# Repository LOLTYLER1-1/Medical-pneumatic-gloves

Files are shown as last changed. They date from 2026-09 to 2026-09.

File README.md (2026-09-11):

# 医用气动辅助手套 (Medical Pneumatic Assistive Glove)

> 基于 **正点原子领航者 V3.9 ZYNQ7020** + **7" 800×480 触摸 LCD** 的手指被动康复训练装置
> PL(FPGA) + PS(ARM) 协同实现，不依赖外部 MCU
> 创建：2026-05-11 ｜ 最新修订：2026-08-16（台架联调打通）

---

## 项目简介

面向脑卒中后手指屈曲挛缩、神经损伤患者的手指 **被动屈伸训练** 装置：

- **摸左半屏** → 气泵加压到设定值（默认 50 kPa）自动停止，手套气室鼓胀带动手指屈曲
- **摸右半屏** → 泄气阀打开，自然回弹松手
- LCD 实时显示压力数值（`XXX.XX KPA` 大字）、状态色条、压力条
- **三层安全保护**：PL 端纯组合逻辑硬件强切（≥80 kPa 泵阀双断）、板载 KEY1 急停、
  传感器故障检测（通信失败 2~3 秒内蜂鸣 + 自动泄气锁定）
- 泄气阀选用 **常开型 (NO)**：断电自动泄压，fail-safe

### 工作原理一句话

```
摸 LCD → GT911(PS 端 EMIO 软件 IIC) → ZYNQ7020 → PCB 驱动板 → 气泵/泄气阀 → 手套气室
                                        ↑                    │
                                        └── XGZP6857D 气压传感器 (IIC 闭环反馈) ──┘
```

📹 **演示视频**：
- [`无气压传感器版实验演示_2026-09-04.mp4`](./无气压传感器版实验演示_2026-09-04.mp4)（无气压传感器版本实验，2026-09-04）
- [`简易版实验结果演示.mp4`](./简易版实验结果演示.mp4)（仿真压力模式，气球抓握演示，2026-08）
🖼️ **定稿电路图**：[`最终电路图.png`](./最终电路图.png)

---

## 当前状态（2026-08-16）

| 项 | 状态 |
|---|---|
| PL 端 13 个 Verilog 模块 + XDC + 比特流 | ✅ 完成并上板验证 |
| GT911 触摸（复位时序根因已修复） | ✅ 左右半屏充/泄请求完好 |
| PS 端 Vitis 应用（EMIO / DCC 日志 / 心跳 LED） | ✅ 完成 |
| 驱动板 PCB（立创EDA 工程 + Gerber，三重验证） | ✅ 2026-07-30 完成 |
| 台架联调（仿真压力模式气球演示） | ✅ 2026-08-04 成功 |
| 真实压力闭环 | ⏳ 等重买 XGZP6857D **IIC 数字版**（旧传感器疑似焊接烫死），到手后 `SIM_PRESSURE` 改 0 |
| 遗留硬件 | ⏳ 12V GND 与 ATK GND 需并 2~3 根地线（治地弹负尖峰）；ULN2803 COM 接 12V 待确认 |

---

## 仓库结构

```
medical project/
├─ README.md                        ← 本文件
├─ 最终电路图.png                    ← 定稿电路图 (4400×3300, 全元件覆盖)
├─ 简易版实验结果演示.mp4             ← 台架演示视频 (2026-08)
├─ 无气压传感器版实验演示_2026-09-04.mp4 ← 无气压传感器版实验视频 (2026-09-04)
├─ lcd_image.coe                    ← LCD 中心图片初始化文件 (200×175 RGB565)
│
├─ 01_思维导图/项目思维导图.md         ← 系统全景、里程碑、开发顺序
├─ 02_原理图/
│   ├─ 系统原理图.md                 ← 框图/气路/电气连接/引脚表/台架联调记录
│   └─ gen_final_circuit.py         ← 定稿电路图生成脚本 (改后重跑出新图)
│
├─ 03_元件清单/
│   ├─ 元件采购清单.md               ← 采购方案与注意事项
│   ├─ 最终元件清单_2026-07-21.md/.png  ← ★ 权威 BOM
│   ├─ 淘宝直搜词清单_2026-07-22.md/.png ← 下单搜索关键词
│   └─ XGZP6857D_引脚图.png          ← 传感器引脚辨别图
│
├─ 05_FPGA_PL/                      ← PL 端 Verilog (Vivado 2020.2)
│   ├─ 00_top/ ~ 12_pressure_model/ ← 13 个模块, 每个都有干净版+逐行注释教学版
│   ├─ constraints/medical_glove.xdc
│   ├─ sim/                         ← Testbench + Python 事务级/比特级仿真脚本
│   └─ README.md                    ← Vivado 工程重建步骤 (IP/BD 配置)
│
├─ 06_PS/                           ← PS 端 ARM 软件 (Vitis 2020.2)
│   ├─ system_top.xsa               ← 硬件移交文件 (含比特流)
│   └─ VITIS/medical_glove_app/src/ ← 应用源码 (main/ft5206/touch/myiic/emio_iic_cfg)
│
└─ 07_PCB/                          ← 驱动板 PCB (立创EDA 专业版)
    ├─ 医用手套驱动板.epro            ← 完整工程, 可直接打开/编辑/下单
    ├─ 医用手套驱动板_gerber.zip       ← 打板生产文件 (2层 90×68mm 全直插)
    ├─ 验证报告.md / 下单与使用指南.md
    └─ gen_pcb.py 等                 ← PCB 自动生成与校验脚本
```

---

## 硬件连接要点（ATK MODULE U4 排针，唯一外接点）

ATK 口丝印是历史名称（UART 模块用），实际就是 4 个普通 FPGA IO：

| ATK 丝印 | FPGA 引脚 | 本项目信号 |
|---|---|---|
| LED | N15 | 气压传感器 SCL |
| KEY | G14 | 气压传感器 SDA |
| RXD | T19 | 气泵驱动 (→100R→IRLZ44N 栅极) |
| TXD | J15 | 泄气阀驱动 (→ULN2803 IN1) |
| GND | — | 共地（**12V 适配器负极必须接这里，并 2~3 根地线**） |
| VCC | — | +5V（仅传感器/上拉电源，禁带泵阀） |

板载资源（免外接）：LED0=H15 状态/心跳，KEY1=K16 急停，蜂鸣器=M14 告警，KEY_RST=N16 复位。

---

## 快速开始

1. 读文档：[思维导图](./01_思维导图/项目思维导图.md) → [系统原理图](./02_原理图/系统原理图.md) → [元件清单](./03_元件清单/最终元件清单_2026-07-21.md)
2. PL 重建：按 [`05_FPGA_PL/README.md`](./05_FPGA_PL/README.md) 新建 Vivado 2020.2 工程
   （器件 `xc7z020clg400-2`，需配 `clk_wiz_0` + `lcd_image_rom` 两个 IP + PS7 Block Design）
3. PS 重建：Vitis 2020.2 导入 `06_PS/system_top.xsa`，新建应用加入 `06_PS/VITIS/medical_glove_app/src/`
4. 无传感器演示：`medical_glove_top.v` 中 `SIM_PRESSURE=1`（仿真压力模型顶替传感器）；
   传感器到位后改 0 恢复真实闭环
5. 打板：`07_PCB/医用手套驱动板_gerber.zip` 直接上传嘉立创下单

---

## 安全声明

⚠️ 本项目为 **学习实验作品**，不是医疗器械，禁止替代正规康复治疗。
任何穿戴测试前，必须先用气球/瓶罐做负载验证；压力硬上限 80 kPa 由 PL 纯组合逻辑强切，
泄气阀断电自动打开（fail-safe）。

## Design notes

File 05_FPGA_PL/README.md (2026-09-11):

# 05_FPGA_PL端 - Verilog 工程

> 医用气动辅助手套 - ZYNQ7020 PL 端
> 工具链: Vivado 2020.2
> 顶层模块: **`00_top/medical_glove_top.v`** ★

---

## 一、文件结构

```
05_FPGA_PL/
├── README.md                                  本文件
├── 00_top/
│   ├── medical_glove_top.v                    顶层 (综合用, 含 SIM_PRESSURE 参数)
│   ├── medical_glove_top_annotated.v          顶层 (教学版)
│   └── system_top.v                           连接 BD wrapper + glove 顶层的包装
├── 01_clock_reset/                            时钟/复位 (依赖 clk_wiz_0)
├── 02_key_debounce/                           按键消抖
├── 03_lcd_timing/                             LCD 行场时序
├── 04_lcd_display/                            UI 渲染 (含压力数值 BCD 字库)
├── 05_touch_iic/                              触摸 IIC 主机 (★ 早期方案, 最终触摸走 PS EMIO)
├── 06_pressure_iic/                           XGZP6857D 气压 IIC 主机 (官方规格书重写版)
├── 07_pwm_ctrl/                               气泵软启动 PWM
├── 08_glove_fsm/                              主状态机
├── 09_safety_interlock/                       硬件安全联锁 (纯组合)
├── 10_axi_lite_reg/                           EMIO 旁路寄存器
├── 11_buzzer/                                 蜂鸣器 2Hz 告警 (板载 M14)
├── 12_pressure_model/                         仿真压力模型 (SIM_PRESSURE=1 时顶替传感器)
├── ip_sources/lcd_image.coe                   屏幕中心图片初始化文件 (200x175 RGB565)
├── constraints/medical_glove.xdc              引脚约束
├── sim/                                       Testbench + Python 仿真验证脚本
├── vivado_bd_emio_fix.tcl                     BD EMIO 修复脚本
└── 用户操作清单.docx                           Vivado 操作步骤记录
```

每个子目录里:
- `xxx.v`           = 干净版 (加入 Vivado 工程综合)
- `xxx_annotated.v` = 教学版 (每行注释, **不要加入工程**)

---

## 二、需要在 Vivado 中创建的 IP 核

需要 **2 个 IP** + **PS7 (Block Design 添加)**:

### IP 1: Clocking Wizard `clk_wiz_0`

**作用**: 50 MHz → 100 MHz + 33.33 MHz

**创建步骤**:
1. Vivado → `IP Catalog` → 搜索 `Clocking Wizard` → 双击
2. 在 `Clocking Options` 选项卡:
   - Primary: `Single ended clock capable pin`
   - Source frequency: `50.000` MHz
3. 在 `Output Clocks` 选项卡:
   - `clk_out1` 勾选, 频率填 `100.000`
   - `clk_out2` 勾选, 频率填 `33.333`
   - `reset type` 选 `Active Low` (与 RTL 中的 `resetn` 端口匹配)
   - 勾选 `locked` 输出
4. Component Name 保持默认 `clk_wiz_0` → OK → Generate

### IP 2: Block Memory Generator `lcd_image_rom` (屏幕中心图片)

**作用**: 存放 200x175 RGB565 图片, 给 `lcd_display.v` 模块读取

**创建步骤**:
1. Vivado → `IP Catalog` → 搜索 `Block Memory Generator` → 双击
2. `Component Name` 必须填 **`lcd_image_rom`** (与 lcd_display.v 例化名一致)
3. `Basic` 选项卡:
   - Interface Type: `Native`
   - Memory Type: **`Single Port ROM`**
4. `Port A Options` 选项卡:
   - Port A Width: **`16`**  (RGB565)
   - Port A Depth: **`35000`** (= 200 × 175)
   - Enable Port Type: `Always Enabled`
   - **取消勾选** `Primitive Output Register` (减少 1 拍延迟; 不取消则需要再加 1 级 pipeline)
   - 实际默认 1 拍延迟即可, RTL 代码已按 1 拍延迟对齐
5. `Other Options` 选项卡:
   - **勾选** `Load Init File`
   - Coe File: 点 `Browse` 选 `<工程目录>/ip_sources/lcd_image.coe`
   - 等校验通过 (会显示像素数 = 35000)
6. → OK → Generate Output Products

**图片位置**:
- 屏幕中心 (300, 152) → (499, 326)
- 屏幕 800×480 减图片 200×175 居中

**RGB565 → RGB888**: 由 RTL 自动做位扩展, 不需关心

### Block Design 中: ZYNQ7 Processing System (PS7)

PS7 不是"创建", 是在 Block Design 里拖一个 IP 进去:

1. `Create Block Design` → 名字 `system`
2. 右键空白 → `Add IP` → 选 `ZYNQ7 Processing System`
3. 双击 PS7 IP 弹出配置:
   - **MIO Configuration**:
     - 关掉所有用不到的(例如 USB/Ethernet/SDIO 按板子实际可用情况)
     - 保留 UART1 (Vitis 串口打印用)
   - **PS-PL Configuration → General → Enable Clock Resets → FCLK_RESET0_N**: 勾选
   - **PS-PL Configuration → AXI Non Secure Enablement → GP Master AXI**: 勾选 M_AXI_GP0
   - **MIO Configuration → I/O Peripherals → GPIO → EMIO GPIO Width**: 填 `64`
     (最终映射: 输出 EMIO[0]=grip_req, [1]=release_req, [17:2]=setpoint(0.01kPa);
      输入 EMIO[15:0]=压力, [18:16]=FSM状态, [19]=safety_trigger, [20]=sensor_fault;
      触摸 IIC 走 EMIO[54:57] = XGpioPs pin 108~111)
   - **Clock Configuration → PL Fabric Clocks → FCLK_CLK0**: 50 MHz (与 PL 系统时钟一致, 但实际我们用板上有源晶振, 这里 FCLK_CLK0 可以不接, 留默认)
4. 点 `Run Block Automation` → 自动连复位

### (可选) Integrated Logic Analyzer `ila_0` - 调试用

仅在仿真后还需在板上抓信号时添加。本工程不强制依赖。

---

## 三、Vivado 工程创建完整步骤

### 1) 新建工程
- File → New Project → Project Type: `RTL Project`
- Default Part: `xc7z020clg400-2`

### 2) 添加源文件 (只添加干净版, 不要添加 `_annotated.v`)
- `Add Sources` → `Add or create design sources`
- 选 13 个子目录里的干净版 .v 文件 (顶层 + system_top + 12 个子模块)
- 添加约束: `constraints/medical_glove.xdc`

### 3) 添加 IP
- `IP Catalog` → Clocking Wizard → 按 §二 IP1 参数配置 → Generate Output Products
- `IP Catalog` → Block Memory Generator → 按 §二 IP2 参数配置 (COE 选 `ip_sources/lcd_image.coe`) → Generate Output Products

### 4) 创建 Block Design
- `Create Block Design` → 加 PS7 → 配置 EMIO GPIO Width = 20
- 把 PS7 的 EMIO GPIO 端口 Make External
- 默认名 `GPIO_0` → 后续顶层需要修改, 见下一节

### 5) 顶层例化 PS7 (二选一)

**方案 A (推荐)**: 把 medical_glove_top.v 当作纯 PL 顶层, PS7 在 Block Design 里通过 EMIO 单向输出/输入信号, 然后在 Block Design 外部再写一个新顶层把两者拼在一起。

**方案 B**: 直接让 BD wrapper 当工程顶层, 在 BD 里例化 medical_glove_top 作为子 IP (需要 Package IP)。

**当前建议**: 调试期用 **方案 A** 快, 后续可重构。

### 6) 综合 / 实现 / 生成比特流
- `Run Synthesis` → 检查 timing
- `Run Implementation`
- `Generate Bitstream`

### 7) 导出硬件给 Vitis
- `File → Export → Export Hardware` → 勾选 Include bitstream
- 进入 `06_PS端软件/` 创建 Vitis 工程

---

## 四、模块层级图

```
                medical_glove_top.v  ★顶层★
                          │
   ┌──────────┬───────────┼───────────┬──────────┬──────────┐
   │          │           │           │          │          │
clock_reset key_debounce lcd_timing lcd_display touch_iic glove_fsm
   │                                              │          │
   └─►clk_wiz_0(IP)                               │          │
                                                  │          │
                                            pressure_iic  pwm_ctrl
                                                            │
                                                       safety_interlock
                                                            │
                                                  (pump_o/v1_o/v2_o)
                          │
                  axi_lite_reg ←──── EMIO ────► PS7 (ARM A9)
```

---

## 五、模块职责一览

| # | 模块 | 角色 | Arduino 类比 |
|---|---|---|---|
| 0 | medical_glove_top ★ | 顶层 | `.ino` 主文件 |
| 1 | clock_reset | 时钟生成 + 复位同步 | 内部定时器 |
| 2 | key_debounce | 物理按键 20ms 消抖 | 按键防抖代码 |
| 3 | lcd_timing | LCD 行场时序 | 屏库底层 |
| 4 | lcd_display | UI 渲染 | tft.fillRect |
| 5 | touch_iic | 触摸 IIC (早期方案, 最终走 PS EMIO 软 IIC, GT911) | Wire.h |
| 6 | pressure_iic | XGZP6857D 读气压 (官方规格书重写版, 带故障检测) | Wire.h 读 BMP |
| 7 | pwm_ctrl | 气泵软启动 PWM | analogWrite() |
| 8 | glove_fsm | 主状态机 | switch(state) |
| 9 | safety_interlock | 硬件安全联锁 | 物理保险丝 |
| 10 | axi_lite_reg | EMIO 接口 | Serial.print() |
| 11 | buzzer_ctrl | 蜂鸣器 2Hz 告警 (M14) | tone() |
| 12 | pressure_model | 仿真压力模型 (演示用) | 假传感器 |

---

## 六、代码风格约定

### 端口命名后缀
- `_i` — input
- `_o` — output
- `_io` — inout (仅 IIC 用)
- `_n` — 低电平有效 (如 `rst_n_i`)

### 信号命名中缀
- `_raw` — 原始信号
- `_clean` — 消抖/同步后
- `_sync` — 跨时钟域同步后

### 双版本约定
- 干净版 `xxx.v` (综合用)
- 教学版 `xxx_annotated.v` (每行注释, 仅作学习)

---

## 七、当前进度 (2026-08-16)

- ✅ 文件夹结构
- ✅ 顶层 medical_glove_top.v 双版本 (含 SIM_PRESSURE 仿真压力开关)
- ✅ 全部 13 个子模块双版本完成 (含 buzzer_ctrl / pressure_model)
- ✅ XDC 约束 (基于官方 NAVIGATOR_ZYNQ_IO.xdc, 已 1:1 对齐; false_path 用通配符 `clk_out*_clk_wiz_0*`)
- ✅ COE 图片资源 (ip_sources/lcd_image.coe, 200x175 RGB565)
- ✅ Vivado IP 生成 (clk_wiz_0 + lcd_image_rom)
- ✅ Block Design (PS7 + EMIO GPIO 64 位)
- ✅ 综合 + 实现 + Bitstream (已上板)
- ✅ 仿真 Testbench + Python 验证脚本 (sim/, 压力序列/BCD 字库/比特级 IIC 全过)
- ✅ 台架联调 (2026-08-04, 仿真压力模式气球演示成功)
- ⏳ 真实传感器闭环 (等重买 XGZP6857D 数字版, SIM_PRESSURE 改 0)

---

## 八、下一步行动

按以下顺序在 Vivado 里操作:

1. 新建工程 (xc7z020clg400-2)
2. 添加 11 个干净版 .v 文件 + medical_glove.xdc
3. 创建 IP: clk_wiz_0 + lcd_image_rom (按本文 §二配置)
4. 创建 Block Design 加 PS7
5. 写一个新顶层(top_wrapper.v)把 medical_glove_top 和 BD wrapper 连接
6. 跑综合, 看时序是否过, 修复警告
7. 实现 + 生成 bitstream
8. 导出 XSA 给 Vitis 用

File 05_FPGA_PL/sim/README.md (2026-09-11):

# PL 端仿真文件说明

## 文件清单

| 序号 | Testbench | 被测模块 | 说明 |
|---|---|---|---|
| 1 | `tb_safety_interlock.v` | safety_interlock | 纯组合逻辑，测试压力阈值触发 |
| 2 | `tb_axi_lite_reg.v` | axi_lite_reg | 打拍寄存器，测试 EMIO 旁路 |
| 3 | `tb_buzzer_ctrl.v` | buzzer_ctrl | 2Hz 蜂鸣器，仿真时提速到 1kHz |
| 4 | `tb_glove_fsm.v` | glove_fsm | 5 态状态机，测试各状态转换 |
| 5 | `tb_pwm_ctrl.v` | pwm_ctrl | PWM + 软启动，仿真时缩短 ramp 时间 |
| 6 | `tb_key_debounce.v` | key_debounce | 按键消抖，仿真时缩到 1ms |
| 7 | `tb_lcd_timing.v` | lcd_timing | LCD 时序，用小参数快速验证一帧 |
| 8 | `tb_clock_reset.v` | clock_reset | 时钟+复位，用 mock 替代 clk_wiz_0 IP |
| 9 | `tb_lcd_display.v` | lcd_display | LCD 渲染，用 mock 替代 BROM IP |
| 10 | `tb_touch_iic.v` | touch_iic | 触摸 IIC，配合 i2c_slave_bfm |
| 11 | `tb_pressure_iic.v` | pressure_iic | 气压 IIC，配合 i2c_slave_bfm |
| 12 | `tb_medical_glove_top.v` | medical_glove_top | 顶层集成测试，含所有 mock |
| - | `i2c_slave_bfm.v` | (辅助模块) | IIC 从设备行为模型，供 10/11/12 使用 |

## Vivado 仿真步骤

1. 打开 Vivado 工程
2. **Add Sources** -> **Add Simulation Sources**
3. 选择 `sim/` 目录下的 `.v` 文件（根据要测的模块选择对应的 tb）
4. 在 **Simulation Sources** 中右键对应 testbench -> **Set as Top**
5. 点击 **Run Simulation** -> **Run Behavioral Simulation**
6. 在波形窗口中添加需要观察的信号，运行仿真

## iverilog + GTKWave (免费方案)

如果安装了 iverilog 和 GTKWave，可以用以下命令行编译运行：

```bash
# 进入 sim 目录
cd "D:\medical project\05_FPGA_PL端\sim"

# 例：编译并运行 safety_interlock 的 testbench
iverilog -o safety_interlock.vvp ../09_safety_interlock/safety_interlock.v tb_safety_interlock.v
vvp safety_interlock.vvp
gtkwave safety_interlock.vcd

# 例：运行 clock_reset（需要 mock clk_wiz_0）
iverilog -o clock_reset.vvp ../01_clock_reset/clock_reset.v tb_clock_reset.v
vvp clock_reset.vvp

# 例：运行 top 级集成测试（需要所有子模块 + mocks）
iverilog -o top.vvp \
  ../00_top/medical_glove_top.v \
  ../01_clock_reset/clock_reset.v \
  ../02_key_debounce/key_debounce.v \
  ../03_lcd_timing/lcd_timing.v \
  ../04_lcd_display/lcd_display.v \
  ../05_touch_iic/touch_iic.v \
  ../06_pressure_iic/pressure_iic.v \
  ../07_pwm_ctrl/pwm_ctrl.v \
  ../08_glove_fsm/glove_fsm.v \
  ../09_safety_interlock/safety_interlock.v \
  ../10_axi_lite_reg/axi_lite_reg.v \
  ../11_buzzer/buzzer_ctrl.v \
  i2c_slave_bfm.v tb_medical_glove_top.v
vvp top.vvp
```

## 文件命名约定

- `tb_xxx.v` = 干净版 testbench（无注释，直接用于仿真）
- `tb_xxx_annotated.v` = 教学版（每行注释，学习用，**不加入 Vivado 工程**）

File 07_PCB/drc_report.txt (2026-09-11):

** Drc report for board.kicad_pcb **
** Created on 2026-07-30T21:47:53 **
** Report includes: Errors, Warnings, Exclusions **

** Found 24 DRC violations **
[starved_thermal]: 缓释热焊盘 (花焊盘) 与填充区的连接不完整 (层 Bottom Layer; 1 条引线与死铜相连)
    Local override; error
    @(99.8730 mm, 69.8730 mm): Zone [GND] on Bottom Layer, priority 0
    @(112.0000 mm, 95.8100 mm): PTH pad 5 [GND] of J1
[lib_footprint_issues]: 当前配置中不包含封装库 '医用手套驱动板-easyedapro'
    Local override; warning
    @(112.0000 mm, 116.0000 mm): Footprint J2
[lib_footprint_issues]: 当前配置中不包含封装库 '医用手套驱动板-easyedapro'
    Local override; warning
    @(156.0000 mm, 82.0000 mm): Footprint C1
[lib_footprint_issues]: 当前配置中不包含封装库 '医用手套驱动板-easyedapro'
    Local override; warning
    @(166.0000 mm, 122.0000 mm): Footprint D1
[lib_footprint_issues]: 当前配置中不包含封装库 '医用手套驱动板-easyedapro'
    Local override; warning
    @(130.0000 mm, 82.0000 mm): Footprint U1
[lib_footprint_issues]: 当前配置中不包含封装库 '医用手套驱动板-easyedapro'
    Local override; warning
    @(148.0000 mm, 82.0000 mm): Footprint C2
[lib_footprint_issues]: 当前配置中不包含封装库 '医用手套驱动板-easyedapro'
    Local override; warning
    @(148.0000 mm, 82.0000 mm): Footprint C2
[lib_footprint_issues]: 当前配置中不包含封装库 '医用手套驱动板-easyedapro'
    Local override; warning
    @(164.0000 mm, 110.0000 mm): Footprint D2
[lib_footprint_issues]: 当前配置中不包含封装库 '医用手套驱动板-easyedapro'
    Local override; warning
    @(150.0000 mm, 122.0000 mm): Footprint Q1
[lib_footprint_issues]: 当前配置中不包含封装库 '医用手套驱动板-easyedapro'
    Local override; warning
    @(112.0000 mm, 92.0000 mm): Footprint J1
[lib_footprint_issues]: 当前配置中不包含封装库 '医用手套驱动板-easyedapro'
    Local override; warning
    @(166.0000 mm, 82.0000 mm): Footprint T3
[lib_footprint_issues]: 当前配置中不包含封装库 '医用手套驱动板-easyedapro'
    Local override; warning
    @(166.0000 mm, 82.0000 mm): Footprint T3
[lib_footprint_issues]: 当前配置中不包含封装库 '医用手套驱动板-easyedapro'
    Local override; warning
    @(166.0000 mm, 82.0000 mm): Footprint T3
[lib_footprint_issues]: 当前配置中不包含封装库 '医用手套驱动板-easyedapro'
    Local override; warning
    @(148.0000 mm, 99.0000 mm): Footprint U2
[lib_footprint_issues]: 当前配置中不包含封装库 '医用手套驱动板-easyedapro'
    Local override; warning
    @(126.0000 mm, 92.0000 mm): Footprint R1
[lib_footprint_issues]: 当前配置中不包含封装库 '医用手套驱动板-easyedapro'
    Local override; warning
    @(126.0000 mm, 92.0000 mm): Footprint R1
[lib_footprint_issues]: 当前配置中不包含封装库 '医用手套驱动板-easyedapro'
    Local override; warning
    @(126.0000 mm, 92.0000 mm): Footprint R1
[lib_footprint_issues]: 当前配置中不包含封装库 '医用手套驱动板-easyedapro'
    Local override; warning
    @(126.0000 mm, 92.0000 mm): Footprint R1
[silk_overlap]: Silkscreen clearance
    Rule: <电路板配置> 中的 "丝印" 约束; warning
    @(146.5000 mm, 79.8000 mm): Segment of C2 on Top Silkscreen Layer
    @(120.0000 mm, 123.5000 mm): PCB text 'C3' on Top Silkscreen Layer
[silk_overlap]: Silkscreen clearance
    Rule: <电路板配置> 中的 "丝印" 约束; warning
    @(146.2000 mm, 120.0000 mm): Segment of Q1 on Top Silkscreen Layer
    @(150.0000 mm, 119.5000 mm): PCB text 'Q1' on Top Silkscreen Layer
[silk_overlap]: Silkscreen clearance
    Rule: <电路板配置> 中的 "丝印" 约束; warning
    @(146.5000 mm, 79.8000 mm): Segment of C2 on Top Silkscreen Layer
    @(148.0000 mm, 79.5000 mm): PCB text 'C2' on Top Silkscreen Layer
[silk_over_copper]: Silkscreen clipped by solder mask
    Local override; warning
    @(161.5000 mm, 86.0000 mm): Segment of T3 on Top Silkscreen Layer
    @(172.3500 mm, 122.0000 mm): PTH pad 2 [+12V] of D1
[silk_over_copper]: Silkscreen clipped by solder mask
    Local override; warning
    @(151.5075 mm, 81.7375 mm): Segment of C1 on Top Silkscreen Layer
    @(150.5400 mm, 82.0000 mm): PTH pad 2 [GND] of C2
[silk_over_copper]: Silkscreen clipped by solder mask
    Local override; warning
    @(151.7600 mm, 83.5075 mm): Segment of C1 on Top Silkscreen Layer
    @(150.5400 mm, 82.0000 mm): PTH pad 2 [GND] of C2

** Found 0 unconnected pads **

** Found 0 Footprint errors **

** Ignored checks **
    - Footprint has no courtyard defined
    - Track endpoint not centered on via
    - Tuning profile track geometries
    - Footprint doesn't match symbol's footprint filters
    - Footprint component type doesn't match footprint pads

** End of Report **

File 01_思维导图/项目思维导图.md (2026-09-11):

# 医用气动辅助手套 - 项目思维导图

> 基于 正点原子领航者 ZYNQ7020 + 800×480 触摸 LCD 的医用气动辅助手套
> 创建日期：2026-05-11
> 修订：2026-05-13（★ 砍 V1 充气阀, ULN2803 焊接洞洞板, 板载蜂鸣器告警）
> 修订：2026-08-16（★ 驱动板 PCB 化(07_PCB), 触摸芯片实为 GT911, 仿真压力模型, 台架联调打通）

---

## 一、项目总览（Mermaid 思维导图）

> 在 VS Code 中安装 "Markdown Preview Mermaid Support" 插件即可可视化预览。

```mermaid
mindmap
  root((医用气动<br/>辅助手套))
    [1.项目目标]
      被动屈伸训练
      "+" 加压抓握
      "-" 减压松手
      LCD 触摸交互
      压力闭环安全
    [2.系统组成]
      上位机 LCD HMI
        加号按钮
        减号按钮
        压力实时显示
        档位/进度条
      ZYNQ7020 控制核心
        PS 端 ARM Cortex-A9
        PL 端 FPGA 逻辑
      执行机构
        微型气泵
        ★ 仅泄压电磁阀 V2 NO
        ★ 砍 V1 充气阀
        软体手指/手套气室
      传感反馈
        XGZP6857D IIC 气压
      板载资源-不外接
        ★ LED0-H15 状态
        ★ KEY1-K16 急停
        ★ 蜂鸣器-M14 告警
      电源系统
        12V/2A 适配器
        +5V 从 ATK Pin6 取
        +3.3V 用模块板载 LDO
    [3.PL端硬件逻辑]
      LCD RGB 时序生成
      ★ 触摸由 PS 端 EMIO 软件 IIC 驱动 (GT911)
      图层叠加显示
      按键消抖
      PWM 软启动
      EMIO GPIO 旁路
      ★ 蜂鸣器 2Hz 调制 buzzer_ctrl
      safety_interlock 硬件强切
      ★ pressure_model 仿真压力 (传感器缺席时演示用)
    [4.PS端软件]
      LCD UI 刷新
      触摸事件分发
      档位状态机
      压力闭环 PID
      安全保护任务
      看门狗
    [5.通信总线]
      EMIO GPIO 旁路 21 位
      预留 AXI4-Lite
    [6.安全机制]
      上限压力 80kPa
      下限压力 0kPa
      过压硬件切断 safety_interlock
      ★ 过压触发蜂鸣器告警
      ★ 急停 KEY1 触发蜂鸣器告警
      软件急停
      硬件机械泄压
      看门狗复位
    [7.开发阶段]
      需求分析 ✅
      硬件选型 ✅
      洞洞板原型 ✅ → ★ 正式 PCB (07_PCB 立创EDA)
      PL 端 Vivado 工程 ✅ 13 模块
      PS 端 Vitis 应用 ✅
      ★ 台架联调 ✅ 2026-08-04 气球演示成功
      穿戴安全验证 ⏳ 待传感器重买后闭环
```

---

## 二、文本结构展开（树形大纲）

```
医用气动辅助手套项目
│
├─ 1. 项目目标
│   ├─ 1.1 功能需求
│   │   ├─ "+" 按钮：气泵加压 → 软体手指弯曲 → 抓握
│   │   ├─ "-" 按钮：泄压阀打开 → 软体手指回弹 → 松手
│   │   ├─ LCD 显示当前压力 (kPa)、档位、状态
│   │   └─ 触摸按键面积 ≥ 80×80 px，便于患者操作
│   ├─ 1.2 性能指标
│   │   ├─ 工作压力：0 ~ 80 kPa（柔性安全范围）
│   │   ├─ 响应时间：< 500 ms
│   │   ├─ 显示刷新率：≥ 30 FPS
│   │   └─ 压力控制精度：±2 kPa
│   └─ 1.3 适用场景
│       ├─ 脑卒中后手指屈曲挛缩康复
│       ├─ 末梢神经损伤被动训练
│       └─ 高校 / 个人实验性研究
│
├─ 2. 系统硬件架构
│   ├─ 2.1 主控：ZYNQ7020（XC7Z020CLG400-2）
│   │   ├─ PS：双核 ARM Cortex-A9，跑裸机或 FreeRTOS
│   │   └─ PL：85K 逻辑单元，跑 LCD/IIC/PWM/蜂鸣器逻辑
│   ├─ 2.2 人机界面：7" 800×480 RGB 电容触摸屏（★ 触摸芯片实为 GT911,
│   │       由 PS 端 EMIO 软件 IIC 驱动, 驱动文件沿用官方 ft5206.c 命名）
│   ├─ 2.3 气动执行 (★ 砍 V1 简化版)
│   │   ├─ 微型隔膜气泵（12V，约 1.5~3 L/min）
│   │   ├─ ~~二位三通常闭电磁阀 V1（充气控制）~~ ★ 已砍
│   │   ├─ 二位二通常开电磁阀 V2（泄气控制, 项目唯一主动阀）
│   │   ├─ 普通手套 + 气球/橡胶指套 (低成本气室)
│   │   └─ Φ4 PU 气管 + 快插接头 + 1 个三通 (并联气压传感器)
│   ├─ 2.4 反馈传感
│   │   └─ XGZP6857D 数字 IIC 气压传感器 (0~100 kPa)
│   ├─ 2.5 驱动与电路板 (★ 2026-07-30 已 PCB 化, 见 07_PCB/)
│   │   ├─ 正式 PCB: 2层板 90×68mm, 全直插(仅 AMS1117 为 SOT-223)
│   │   │   立创EDA 工程 医用手套驱动板.epro + Gerber 打板包
│   │   ├─ IRLZ44N 逻辑电平 N-MOSFET (气泵低边驱动)
│   │   ├─ ULN2803APG 达林顿阵列 (DIP-18, 只驱动 V2 阀)
│   │   ├─ 1N4007 ×2 续流二极管 (反向并联在气泵/V2)
│   │   ├─ 4.7K ×2 上拉电阻 (IIC SDA/SCL → +3.3V, PCB J2 已集成)
│   │   ├─ 栅极 100R 串联 + 100K 下拉 (上电默认关泵)
│   │   ├─ KF301-2P 接线端子 (接气泵 +/−、V2 +/−、12V 输入)
│   │   ├─ 6 芯杜邦线 (ATK MODULE U4 → 驱动板)
│   │   └─ 历史: 洞洞板原型已验证 (2026-08 台架), ESD 曾击穿 Q1 栅氧, 已换管修复
│   ├─ 2.6 电源 (★ 简化, 不需要 DC-DC 模块)
│   │   ├─ 12V/2A 开关电源 (驱动气泵和阀)
│   │   ├─ +5V 直接从 ATK MODULE Pin6 引出 (来自 ZYNQ 板)
│   │   ├─ +3.3V 直接用气压传感器模块上的板载 LDO
│   │   └─ 共地: 12V 适配器 − 必须接 ZYNQ GND (ATK Pin5)
│   └─ 2.7 板载资源 (★ 无需采购或外接)
│       ├─ LED0 (H15) - 状态指示
│       ├─ KEY1 (K16) - 急停按键
│       ├─ 蜂鸣器 (M14) - 超压/急停 2Hz 告警
│       ├─ KEY_RST (N16) - 系统复位
│       └─ 50MHz 晶振 (U18) - 主时钟
│
├─ 3. PL 端（FPGA 逻辑）开发 (★ 13 个 .v 模块已写完并上板验证)
│   ├─ 3.1 LCD 控制 (clock_reset / lcd_timing / lcd_display)
│   │   ├─ RGB 时序生成（HSYNC/VSYNC/DE/PCLK）
│   │   ├─ 800×480@60 标准时序
│   │   ├─ 中心 200×175 图片显示 (BROM IP)
│   │   └─ ★ 压力数值显示 (double-dabble BCD + 5×7 字库, "XXX.XX KPA")
│   ├─ 3.2 GT911 触摸 (★ 改由 PS 端 EMIO 软件 IIC 驱动, ft5206.c)
│   │   ├─ 根因已修复: RST 上升沿 INT 电平决定 I2C 地址 (0x5D)
│   │   ├─ PL touch_iic.v 为早期方案, 保留未用
│   │   └─ 左半屏=充气 GRIP / 右半屏=泄气 RELEASE
│   ├─ 3.3 气压传感器 (pressure_iic)
│   │   ├─ XGZP6857D IIC 读取, 地址 0x6D
│   │   ├─ ★ 已按官方规格书重写: RMW 0xA5 + sco 轮询 + 3 次单读 + 系数 1638
│   │   └─ ★ sensor_fault_o 故障检测 (NACK/总线卡低 → EMERGENCY + 蜂鸣)
│   ├─ 3.4 状态机 + PWM (glove_fsm / pwm_ctrl)
│   │   ├─ IDLE/GRIP/HOLD/RELEASE/EMERGENCY
│   │   ├─ 气泵软启动 PWM (500ms 斜坡)
│   │   └─ ★ 回差 2kPa, GRIP→HOLD 判定 >= setpoint
│   ├─ 3.5 EMIO 接口 (axi_lite_reg)
│   │   ├─ EMIO GPIO 旁路 (替代 AXI-Lite)
│   │   └─ 64 位 EMIO: setpoint 16 位 + 压力/状态/故障回读
│   ├─ 3.6 安全联锁 (safety_interlock)
│   │   └─ ≥80kPa 硬件强切 pump=V2=0 (纯组合)
│   ├─ ★ 3.7 蜂鸣器告警 (buzzer_ctrl)
│   │   ├─ 触发: safety_trigger OR ~emerg_key OR sensor_fault
│   │   └─ 输出: 2Hz 间歇方波 → 板载 M14
│   └─ ★ 3.8 仿真压力模型 (pressure_model, 2026-08-03 新增)
│       ├─ SIM_PRESSURE=1 时顶替真实传感器 (开环估算, Q8 定点)
│       ├─ 充气 12.5kPa/s, 泄气 100kPa/s, 保压泄漏 1kPa/s
│       └─ 用途: 传感器缺席时全链路演示 (08-04 气球演示即此模式)
│
├─ 4. PS 端（ARM 软件）开发
│   ├─ 4.1 框架选择
│   │   ├─ 裸机（Vitis SDK）—— 推荐入门
│   │   └─ FreeRTOS（多任务）—— 进阶
│   ├─ 4.2 任务划分
│   │   ├─ Task_UI：界面刷新、按钮检测
│   │   ├─ Task_Control：压力 PID、状态机
│   │   ├─ Task_Sensor：IIC 读传感器
│   │   └─ Task_Safety：超限保护、急停
│   ├─ 4.3 状态机 (★ 砍 V1 后简化)
│   │   ├─ IDLE：待机，泵=0, V2=0(开), 自动泄气
│   │   ├─ GRIP：抓握，泵=1, V2=1(闭), 持续打气
│   │   ├─ HOLD：保持，泵=0, V2=1(闭), 保压
│   │   ├─ RELEASE：松手，泵=0, V2=0(开), 自然回弹
│   │   └─ EMERGENCY: 强切 pump=V2=0 + ★ 蜂鸣器 2Hz 告警
│   └─ 4.4 PID 闭环（可选）
│       ├─ 输入：目标压力 (kPa)
│       ├─ 反馈：传感器压力
│       └─ 输出：PWM 占空比
│
├─ 5. 软件 / 工具链
│   ├─ Vivado 2020.2（PL 端综合实现）
│   ├─ Vitis 2020.2（PS 端应用开发）
│   ├─ PCtoLCD2002（字模/位图生成）
│   ├─ AutoCAD / SolidWorks（机械手套外形）
│   └─ KiCad / 立创 EDA（接口板原理图与 PCB）
│
├─ 6. 开发里程碑 (★ 实际完成情况, 截至 2026-08-16)
│   ├─ ✅ 选型、采购 (2026-05)
│   ├─ ✅ LCD 显示 + GT911 触摸打通 (2026-05-21, 复位时序根因修复)
│   ├─ ✅ PL 端 13 模块 + XDC + 比特流 (2026-05~08)
│   ├─ ✅ PS 端 Vitis 应用 (EMIO 触摸/状态机/DCC 日志)
│   ├─ ✅ 驱动板 PCB 设计打板 (2026-07-30, 07_PCB, 三重验证通过)
│   ├─ ✅ 台架联调 (2026-08-04, 仿真压力模式气球演示成功)
│   ├─ ⏳ 闭环恢复 (等重买 XGZP6857D 数字版, SIM_PRESSURE 改 0)
│   ├─ ⏳ 穿戴测试与安全验证
│   └─ ⏳ 文档整理、视频演示 (简易版演示 mp4 已录)
│
├─ 7. 安全与伦理（重要）
│   ├─ 7.1 压力硬上限：< 100 kPa（避免血管/神经损伤）
│   ├─ 7.2 软上限：80 kPa（safety_interlock 模块硬件强切）
│   ├─ 7.3 紧急停止：板载 KEY1 (K16) - 按下即触发蜂鸣 + 强切
│   ├─ 7.4 泄气备份阀 V2：失电常开 NO（断电自动泄压, fail-safe）
│   ├─ ★ 7.5 蜂鸣器告警：板载 M14 - 超压 OR 急停时 2Hz 间歇响
│   ├─ 7.6 续流二极管：1N4007 反向并联气泵/V2, 阴极朝 +12V
│   ├─ 7.7 共地强制: 12V 适配器 − 必须接 ZYNQ GND
│   ├─ 7.8 仅限学习实验，禁止替代医疗器械
│   └─ 7.9 任何穿戴前先用气球 / 假手测试
│
└─ 8. 风险与挑战
    ├─ 软体手指自制难度大（替代：购买成品手套）
    ├─ 气密性要求高（接头胶水密封）
    ├─ 电磁阀响应时间影响控制精度
    ├─ ZYNQ PL 资源消耗（注意 LUT、BRAM 使用率）
    └─ LCD 触摸校准（电容屏需注意干扰）
```

---

## 三、开发顺序建议

```
阶段 1：环境搭建
  └─ 安装 Vivado / Vitis 2020.2 → 跑通正点原子官方 LCD 触摸例程

阶段 2：单点突破（每个模块单独验证）
  ├─ LCD 显示 "+/-" 两个大按钮
  ├─ 触摸读取坐标，区分按下哪个按钮
  ├─ PL 端输出 GPIO 控制 LED 模拟气泵
  └─ PL 端 IIC 读取 XGZP6857D 气压传感器

阶段 3：硬件接入 (★ 洞洞板原型已验证 → 正式 PCB 已打板)
  ├─ 洞洞板原型: ULN2803 IC 座 + MOSFET + 1N4007 ×2 + 4.7K ×2 + 电源轨 + KF301 端子
  │   (2026-08-03/04 台架联调: 曾遇 Q1 栅氧 ESD 击穿, 换 IRLZ44N 修复;
  │    教训: 勿在布面焊接, 新 MOSFET 先焊 S 极与 100K 下拉最后焊 G 极)
  ├─ 正式 PCB: 07_PCB/医用手套驱动板.epro (立创EDA) + Gerber 打板包
  │   (2层板 90×68mm, J2 已集成 4.7K→3.3V 上拉, 免外接)
  ├─ 杜邦线接 ATK MODULE U4 → 驱动板
  ├─ 万用表测 MOSFET Drain / ULN2803 OUT1 在 grip_req=1 时是否拉低
  ├─ 接气压传感器, 用手挤进气口看屏幕压力变化
  ├─ 接气泵 + V2, 短时通断验证
  └─ 在没人穿戴情况下试运行（用气球/塑料瓶代替手）★ 2026-08-04 已成功

阶段 4：闭环控制
  ├─ 实现 "+" 持续按住 → 持续加压（限幅 80 kPa）✅ (仿真压力模式已验证)
  ├─ 实现 "-" 持续按住 → 持续泄压（直到 0 kPa）✅
  ├─ 显示压力实时数值 (LCD "XXX.XX KPA" 大字) ✅
  └─ ★ 待重买 XGZP6857D 数字版传感器后 SIM_PRESSURE 改 0 恢复真实闭环

阶段 5：穿戴测试 (⏳ 待做)
  ├─ 先用假肢 / 别人健康手测试
  ├─ 录制视频，测量响应时间 (★ 简易版演示 mp4 已录: 仿真模式气球抓握)
  └─ 收集反馈，迭代优化

阶段 6：遗留硬件问题 (2026-08-04 台架记录, 下次开机先确认)
  ├─ 地弹负尖峰: 阀切换时 T19 量到 -2.5V~-3.85V, 12V GND 与 ATK GND 需并 2~3 根地线
  ├─ ULN2803 COM(pin10) 接 12V+ 待确认 (阀线圈续流回路)
  └─ XGZP6857D 需重买 IIC 数字版 (旧传感器疑似焊接烫死; 勿买模拟版)
```

---

## 四、参考资料链接

### 中文资料
- [基于 STM32 的气动康复手套设计](https://blog.csdn.net/Candy5204/article/details/147591019)（STM32 方案可借鉴）
- [正点原子 ZYNQ 之 FPGA 开发指南](https://blog.csdn.net/weixin_55796564/article/details/122340925)（LCD 触摸屏实验）
- [气动软体机器人：结构设计、工作原理与制造工艺](https://zhuanlan.zhihu.com/p/163424462)
- [柔性手部可穿戴康复运动辅助系统](https://www.hanspub.org/journal/paperinformation?paperid=109909)
- [多腔体式仿生气动软体驱动器的设计与制作](https://www.zjujournals.com/gcsjxb/fileup/1006-754X/HTML/1006-754X-2017-24-05-511.htm)

### 商用参考
- [北京软体机器人 Pavlov P105 手部镜像康复训练器](https://softrobottech.com/web/zh/news/2022110405251564457487)
- [康复机器人手套（百度百科）](https://baike.baidu.com/item/%E5%BA%B7%E5%A4%8D%E6%9C%BA%E5%99%A8%E4%BA%BA%E6%89%8B%E5%A5%97/24119414)

### 驱动芯片
- [ULN2003 工作原理及中文资料](https://blog.csdn.net/qq_38410730/article/details/79787766)
- [ULN2803 驱动模块的使用](https://blog.csdn.net/zxm8513/article/details/110286045)

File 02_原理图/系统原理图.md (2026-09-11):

# 医用气动辅助手套 - 原理图集

> 包括：系统框图 / 气动原理图 / 电气连接图 / PL-PS 架构图 / 手套结构图
> ★ 修订 2026-07-06: 砍 V1 + 气泵 MOSFET 驱动 + V2 ULN2803 驱动 + 板载蜂鸣器告警 M14
> ★ 修订 2026-08-16: 驱动板已 PCB 化(07_PCB 立创EDA 工程+Gerber), 触摸芯片实为 GT911(PS 端 EMIO 软件 IIC 驱动)
> 完整电路图 PNG: `D:\medical project\最终电路图.png` (定稿 Rev 2026-07-22, gen_final_circuit.py 重跑出新图)
> ⚠️ 旧版 `电路连接图.png` 已过时, 勿再引用

---

## 一、系统总体框图

```
 ┌───────────────────────────────────────────────────────────────────────┐
 │                    医用气动辅助手套 系统总体框图                       │
 │              (Rev 2026-08-16: 砍 V1, PCB 驱动板, 板载蜂鸣器)           │
 └───────────────────────────────────────────────────────────────────────┘

 ┌────────────────────────────┐              ┌──────────────────────────┐
 │   触摸 LCD (800×480 RGB)   │              │     12V/3A 适配器        │
 │   ┌──────────────────────┐ │              └──────────┬───────────────┘
 │   │   +     压力: 45 kPa │ │                         │
 │   │  ───   档位: ▣▣▢▢▢   │ │                         │ +12V (动力)
 │   │   -    状态: GRIP    │ │                         │
 │   └──────────────────────┘ │                         │
 └─────────────┬──────────────┘                         │
               │ RGB888 + IIC                           │
               │                                        │
               ▼                                        │
 ┌─────────────────────────────────────────────────────────────────────┐
 │                                                                     │
 │            正点原子 领航者 ZYNQ7020 开发板                          │
 │  ┌──────────────────────────┐  ┌────────────────────────────────┐  │
 │  │     PS 端 (ARM A9)       │  │       PL 端 (FPGA)             │  │
 │  │  ─ GT911 触摸 (EMIO 软IIC)│  │  ─ LCD RGB 时序 + 数值显示     │  │
 │  │  ─ 触摸区域→充/泄请求     │◄─┤  ─ 压力数值 BCD 字库渲染       │  │
 │  │  ─ setpoint 写入          │  │  ─ PWM 发生器 (软启动)         │  │
 │  │  ─ 状态/故障 DCC 日志     │  │  ─ EMIO GPIO 旁路 (旁 AXI)     │  │
 │  └──────────────────────────┘  │  ─ 气压传感器 IIC 读取         │  │
 │              ▲                 │  ─ 仿真压力模型 (SIM_PRESSURE)  │  │
 │              │  EMIO           │  ─ 蜂鸣器 2Hz 调制(M14)        │  │
 │              │  EMIO           └──────┬─────────────────────────┘  │
 │              ▼                        │  PL IO                     │
 │  板载: LED0(H15) KEY1(K16) 蜂鸣器(M14)                              │
 │                                       │ ATK MODULE U4 (4GPIO+5V+GND)│
 └─────────────────────────────────────┬───────────────────────────────┘
                                        │ 6 根杜邦线
                                        ▼
                       ┌─────────────────────────────────────┐
                       │  ★ PCB 驱动板 (07_PCB, 90×68mm 2层) │
                       │   IRLZ44N + ULN2803 + 1N4007×2 +     │
                       │   XGZP6857D 气压传感器 + KF301 端子 │
                       │   (J2 已集成 4.7K→3.3V IIC 上拉)     │
                       └────┬──────────┬───────────┬─────────┘
                            │          │           │
                            │+12V/MOS  │+12V/OUT1  │ IIC
                            ▼          ▼           ▼
                  ┌─────────────┐ ┌──────────┐ ┌─────────┐
                  │  微型气泵   │ │ 电磁阀 V2│ │气压传感器│
                  │  12V 1.5L  │ │常开 NO   │ │XGZP6857D│
                  └──────┬──────┘ │2位2通    │ │0-100kPa │
                         │        └────┬─────┘ └────┬────┘
                         │             │            │
                         │             │            │ (并联在气室上)
                         ▼             ▼            │
                  ┌─────────────────────────┐       │
                  │   手套气室 (普通手套 +  │◄──────┘
                  │   气球/橡胶指套作气腔) │
                  └─────────────┬───────────┘
                                │
                                ▼
                          (V2 开 → 泄到大气)
```

> ★ 改动要点 (vs 2026-05-11 初版):
> - 砍 V1 充气阀: 气路从"泵→V1→气室→V2→大气"简化为"泵→气室→V2→大气"
> - 状态指示用板载 LED0 (H15), 不外接
> - 告警用板载有源蜂鸣器 (M14), 不外接
> - ZYNQ 与外设之间唯一连接: ATK MODULE 6-pin 排针 + 6 根杜邦线
> - ★ 驱动板已从洞洞板原型升级为正式 PCB (2026-07-30, 07_PCB/医用手套驱动板.epro + Gerber,
>   2层板 90×68mm 全直插; 洞洞板原型已于 2026-08-04 台架验证全链路)

---

## 二、气动回路原理图 (★ 砍 V1 简化版)

```
 ┌──────────────────────────────────────────────────────────────┐
 │              气动回路原理图 (Pneumatic Schematic)             │
 │              Rev 2026-05-13: 砍 V1 充气阀, 仅留 V2 泄气        │
 └──────────────────────────────────────────────────────────────┘

         大气                                          大气
           │                                            │
           │ (入口)                                     │ (出口)
           ▼                                            ▲
    ┌──────────────┐                              ┌─────┴──────┐
    │ 进气过滤      │                              │ 泄气消音器 │
    │ (5μm 棉芯)   │                              └─────┬──────┘
    └──────┬───────┘                                    │
           │                                            │
           ▼                                            │
    ┌──────────────┐                                    │
    │  微型气泵     │       直接出气                    │
    │  12V/1.5L/min│       (砍 V1 后无充气阀, 由气泵    │
    │  最大 100kPa │       上电 ON/OFF 控制进气)        │
    └──────┬───────┘                                    │
           ▲                                            │
           │                                            │
        泵控信号 (pump_o, T19)                          │
                                                        │
           ▼                                            │
                         ┌──────────────┐               │
                         │ 三通 / 分配  │     泄压控制 │
                         │ (单个三通)   │      ┌───────┴───┐
                         │              │      │ 电磁阀 V2 │
                         │              │◄─────┤ 2位2通 NO │
                         │              │      │ (常开 *)  │
                         └──────┬───────┘      └───────────┘
                                │                   ▲
                                │ Φ4 PU 软管        │ V2 控制信号
                                │                   │ (valve_v2_o, J15)
                                ▼                   │
                  ┌────────────────────────┐        │
                  │  气压传感器 P1         │        │
                  │  XGZP6857D / IIC      │        │
                  │  量程 0~100 kPa       │        │
                  └────────────┬───────────┘        │
                               │                    │
                               ▼                    │
                  ┌────────────────────────┐        │
                  │  手套气室 (普通手套 +  │────────┘
                  │  气球指套, 工作压     │
                  │  力 30~80 kPa)        │
                  └────────────────────────┘

* 注: V2 选用"失电常开"型，断电时自动泄压，保护使用者安全。
  V2 是项目唯一的"主动控制阀", 平时通电关闭, GRIP/HOLD 状态保持气压。
```

### 气路控制逻辑表 (★ 砍 V1 后简化)

| 状态 | 气泵 PUMP | 泄气阀 V2 | 板载 LED | 板载蜂鸣器 | 说明 |
|---|---|---|---|---|---|
| 待机 IDLE | OFF | OFF (开) | 灭 | 静音 | 气泵停, V2 开, 气路泄空 |
| 抓握 GRIP | ON  | ON  (闭) | 亮 | 静音 | 气泵打气, V2 关, 持续加压 |
| 保持 HOLD | OFF | ON  (闭) | 亮 | 静音 | 气泵停, V2 关, 保压 |
| 松手 RELEASE  | OFF | OFF (开) | 灭 | 静音 | 气泵停, V2 开, 自然回弹 |
| 紧急 EMERGENCY| 强切0| 强切0(开)| 灭 | ★ 滴-滴-滴 | KEY1 按下: pump=V2=0 + 蜂鸣 |
| 超压 ≥80kPa | 强切0| 强切0(开)| 灭 | ★ 滴-滴-滴 | safety_interlock 硬件强切 + 蜂鸣 |

> 关键设计：泄气阀 V2 使用 **常开型 (NO)**，断电即泄压，故障安全 (fail-safe)。
> 砍 V1 的代价: 气泵停转时, 残余气压会从气泵进气口慢漏 (但 V2 已经打开,主要泄气路径是 V2)
> 蜂鸣器 (板载 M14): `alarm = safety_trigger | ~emerg_key_clean`, 2Hz 间歇方波

---

## 三、电气连接原理图 (★ MOSFET 气泵 + ULN2803 阀驱动优化版)

> ★ 2026-08-16 注: 本节电路已与 `最终电路图.png` (定稿) 一致, 并已实现为正式 PCB —
> 见 `07_PCB/医用手套驱动板.epro` (立创EDA 工程, 可直接下单) 与 `医用手套驱动板_gerber.zip`。
> PCB 上 J2 已集成 4.7K→3.3V IIC 上拉与去耦电容, 下文"洞洞板"布局描述保留作原型参考。

```
 ┌──────────────────────────────────────────────────────────────────┐
 │              电气连接原理图 (Electrical Schematic)               │
 │              Rev 2026-07-06: 气泵改 MOSFET, V2 保留 ULN2803       │
 └──────────────────────────────────────────────────────────────────┘

  ZYNQ7020 板 (ATK MODULE U4 排针, 唯一外接点)
  ┌────────────────────────────────────────┐
  │  Pin1 N15 [pres_scl_o]  ◄──────────┐   │
  │  Pin2 G14 [pres_sda_io] ◄────────┐ │   │
  │  Pin3 T19 [pump_o]      ─────┐   │ │   │   ← 杜邦线 3+4 (公-母, 6 芯排线)
  │  Pin4 J15 [valve_v2_o]  ──┐  │   │ │   │
  │  Pin5 GND               ──┼──┼───┼─┼───┼──→ 共地
  │  Pin6 +5V               ──┼──┼───┼─┼───┼──→ 传感器/LDO 输入
  └────────────────────────────┼──┼───┼─┼───┘
  板载: KEY1(K16) 急停        │  │   │ │
        LED0(H15) 状态指示    │  │   │ │
        蜂鸣器(M14) 告警      │  │   │ │
                              ▼  ▼   ▼ ▼
  ┌─────────────────────────────────────────────────────────┐
  │   洞洞板 (9×15cm, 全部焊接, 不用面包板)                  │
  │                                                          │
  │   ┌──── 电源轨 (横向) ─────────────────────────────┐    │
  │   │ +3.3V (AMS1117-3.3 或传感器模块 3.3V 输出)         │    │
  │   │ +5V   (来自 ATK Pin6)                            │    │
  │   │ +12V  (来自 12V/3A 适配器+)                       │    │
  │   │ GND   (ATK Pin5 与 12V- 共地)                    │    │
  │   └──────────────────────────────────────────────────┘    │
  │                                                          │
  │      ┌──── 气泵低边驱动: 逻辑电平 N-MOSFET ─────┐       │
  │      │  pump_o(T19) ─ 100R ─► Gate               │       │
  │      │  Gate ─ 100K ─► GND                       │       │
  │      │  Source ─► GND 轨                         │       │
  │      │  Drain  ─► 气泵 −                         │       │
  │      │  气泵 + ─► +12V 轨                        │       │
  │      └──────────────────────────────────────────┘       │
  │                                                          │
  │      ┌──── V2 阀低边驱动: ULN2803APG ───────────┐       │
  │      │  IN1◄── valve_v2_o (J15)  OUT1 ─► V2 阀 −│       │
  │      │  IN2~IN8: 悬空            OUT2~8: 悬空   │       │
  │      │  GND ──► GND 轨           COM ──► +12V 轨│       │
  │      └──────────────────────────────────────────┘       │
  │                                                          │
  │   续流二极管 1N4007/SS14 ×2 (阴极朝 +12V, 反向并联):    │
  │   ┌─ +12V ── 气泵 + ── 气泵 − ── MOSFET Drain          │
  │   │              ▲                                       │
  │   │              └── 二极管阴极在 +12V 这端 ─┐          │
  │   └──────────────────────────────────────────┘          │
  │   ┌─ +12V ── V2阀 + ── V2阀 − ── ULN2803 OUT1          │
  │   │              ▲                                       │
  │   │              └── 二极管阴极在 +12V 这端 ─┐          │
  │   └──────────────────────────────────────────┘          │
  │                                                          │
  │   气压传感器模块 (XGZP6857D, 4-pin 排母焊上):           │
  │       VCC ── +5V 轨                                      │
  │       GND ── GND 轨                                      │
  │       SCL ◄── ATK Pin1 (N15), 经 4.7K 上拉至 +3.3V       │
  │       SDA ◄── ATK Pin2 (G14), 经 4.7K 上拉至 +3.3V       │
  │       若模块自带 5V 上拉: 拆除 5V 上拉或插入 BSS138 转换 │
  │                                                          │
  │   KF301-2P 接线端子 ×3: 接气泵、V2 与 12V 电源输入       │
  └─────────────┬───────────────┬───────────────┬───────────┘
                │               │               │
                ▼               ▼               ▼
        ┌──────────────┐ ┌──────────┐  ┌─────────────┐
        │  微型气泵     │ │ 电磁阀 V2│  │ 12V/3A      │
        │  12V         │ │ 12V NO  │  │ 适配器       │
        │  + −         │ │ + −     │  │ + −         │
        └──────────────┘ └──────────┘  └─────────────┘

注:
  1. 气泵启动电流可能超过 ULN2803 单通道余量, 因此气泵改用逻辑电平 N-MOSFET。
  2. ULN2803 只驱动 V2 阀; COM (Pin10) 必须接 +12V, 不是 +5V。
  3. MOSFET Gate 必须有 100K 下拉, 避免 ZYNQ 上电高阻时误启动气泵。
  4. ATK MODULE Pin6 的 +5V 只给传感器/LDO, 不允许带气泵或阀。
  5. 12V 只进洞洞板动力轨; ZYNQ 与 12V 适配器只共 GND。
  6. SCL/SDA 只能上拉到 3.3V; 若传感器模块自带 5V 上拉, 必须拆上拉或加电平转换。
  7. 去耦电容 (Rev 2026-07-22 补): 100µF 电解 + 104 ×1 并在 下12V轨/GND轨 (靠 T3 电源入口,
     电解长脚=正极朝 12V); 另一只 104 直接焊在传感器排母 VCC−GND 脚间。
```

### ZYNQ 引脚分配表 (★ 真实分配, 与 medical_glove.xdc 一致)

| 信号名 | 方向 | ZYNQ 引脚 | 接线 | 备注 |
|---|---|---|---|---|
| sys_clk_i | IN | U18 | 板载 50MHz 晶振 | 主时钟 |
| sys_rst_n_i | IN | N16 | 板载 KEY_RST | 系统复位 |
| emerg_key_i | IN | K16 | 板载 KEY1 | 急停 (按下=蜂鸣+泄气) |
| lcd_rgb_o[23:0] | OUT | (24 根, 见 XDC) | LCD 排线 | RGB888 |
| lcd_hsync/vsync/de/pclk/bl | OUT | N18/T20/U20/P19/M20 | LCD 排线 | 时序+背光 |
| tp_scl_o | OUT | R19 | LCD 触摸排线 | GT911 SCL (★ 由 PS EMIO 软件 IIC 驱动) |
| tp_sda_io | IO  | P20 | LCD 触摸排线 | GT911 SDA (★ 由 PS EMIO 软件 IIC 驱动) |
| tp_rst_o | OUT | M19 | LCD 触摸排线 | GT911 复位 (RST 上升沿 INT=0 选地址 0x5D) |
| tp_int_i | IN  | U19 | LCD 触摸排线 | GT911 中断 |
| **pres_scl_o** | OUT | **N15** | ATK Pin1 → 杜邦 → 洞洞板 → XGZP6857D SCL | 气压 IIC |
| **pres_sda_io**| IO  | **G14** | ATK Pin2 → 杜邦 → 洞洞板 → XGZP6857D SDA | 气压 IIC |
| **pump_o** | OUT | **T19** | ATK Pin3 → 100R → MOSFET Gate | 气泵控制 |
| **valve_v2_o** | OUT | **J15** | ATK Pin4 → 杜邦 → ULN2803 IN1 | V2 阀控制 |
| led_status_o | OUT | H15 | 板载 LED0 | GRIP/HOLD 亮 |
| **buzzer_o** | OUT | **M14** | 板载有源蜂鸣器 | 超压/急停 滴-滴-滴 |

---

## 四、PL / PS 分工架构图

> ★ 2026-08-16 注: 最终实现采用 **EMIO GPIO 旁路** (64 位, 不用 AXI 寄存器),
> 触摸 IIC 也由 PS 端 EMIO 软件模拟 (GT911 复位时序要求软件精确控制 INT)。
> 下图为早期规划的 AXI 方案, 保留作架构参考。

```
 ┌──────────────────────────────────────────────────────────────────────┐
 │                  ZYNQ7020 内部 PL / PS 协同架构图                    │
 └──────────────────────────────────────────────────────────────────────┘

  ╔══════════════════════════════════════════════════════════════════╗
  ║                          PS 端 (ARM A9)                          ║
  ║  ┌─────────────────┐ ┌─────────────────┐ ┌────────────────────┐  ║
  ║  │ Task_UI         │ │ Task_Control    │ │ Task_Safety        │  ║
  ║  │ - 触摸事件分发  │ │ - PID 闭环      │ │ - 上限保护          │  ║
  ║  │ - LCD 显示刷新  │ │ - 状态机        │ │ - 看门狗            │  ║
  ║  │ - 按钮高亮      │ │ - 设定点更新    │ │ - 急停响应          │  ║
  ║  └────────┬────────┘ └────────┬────────┘ └─────────┬──────────┘  ║
  ║           │                   │                    │             ║
  ║           ▼                   ▼                    ▼             ║
  ║  ┌──────────────────────────────────────────────────────────┐    ║
  ║  │              AXI Interconnect (M_AXI_GP0)                │    ║
  ║  └──────────────────────────────────────────────────────────┘    ║
  ╚══════════════════╤═════════════════╤══════════════╤═════════════╝
                     │                 │              │
        ┌────────────┴──────┐  ┌───────┴───────┐  ┌───┴─────────────┐
        │                   │  │               │  │                 │
        ▼                   ▼  ▼               ▼  ▼                 ▼
  ╔═══════════════════════════════════════════════════════════════════╗
  ║                           PL 端 (FPGA)                            ║
  ║                                                                   ║
  ║  ┌─────────────┐  ┌──────────────┐  ┌──────────────┐             ║
  ║  │ AXI-GPIO    │  │  AXI-Lite    │  │  AXI-Lite    │             ║
  ║  │ 阀/泵控制   │  │  PWM 寄存器  │  │  IIC 寄存器  │             ║
  ║  └──────┬──────┘  └──────┬───────┘  └──────┬───────┘             ║
  ║         │                │                 │                     ║
  ║         ▼                ▼                 ▼                     ║
  ║  ┌─────────────┐  ┌──────────────┐  ┌──────────────┐             ║
  ║  │ 输出 IO     │  │ PWM 发生器   │  │ IIC 主机     │             ║
  ║  │ (PUMP/V1/V2)│  │ (可选调速)   │  │ (气压 + 触摸)│             ║
  ║  └─────────────┘  └──────────────┘  └──────────────┘             ║
  ║                                                                   ║
  ║  ┌─────────────────────────────────────────────────────────┐     ║
  ║  │           LCD 显示控制器 (自主设计 / 官方 IP)            │     ║
  ║  │ - VRAM (DDR3 / BRAM)  → RGB 时序  → LCD 接口            │     ║
  ║  └─────────────────────────────────────────────────────────┘     ║
  ║                                                                   ║
  ║  ┌─────────────────────────────────────────────────────────┐     ║
  ║  │       硬件安全联锁 (Interlock - 纯组合逻辑)              │     ║
  ║  │  IF (压力 > 阈值) THEN PUMP = 0, V2 = 0  (硬件强切)     │     ║
  ║  └─────────────────────────────────────────────────────────┘     ║
  ╚═══════════════════════════════════════════════════════════════════╝
```

---

## 五、软体手指机械结构示意

```
 ┌──────────────────────────────────────────────────────────────┐
 │           软体手指 (PneuNet 弯曲型) 结构剖面示意             │
 └──────────────────────────────────────────────────────────────┘

       充气口                                              指尖
         │                                                  │
         ▼                                                  ▼
   ┌─────┴─────────────────────────────────────────────────────┐
   │█████████████████████████████████████████████████████████ │ ← 顶部硅胶
   │░░░╔═╗░░░╔═╗░░░╔═╗░░░╔═╗░░░╔═╗░░░╔═╗░░░╔═╗░░░╔═╗░░░╔═╗░░░│   (可膨胀)
   │░░░║ ║░░░║ ║░░░║ ║░░░║ ║░░░║ ║░░░║ ║░░░║ ║░░░║ ║░░░║ ║░░░│ ← 气腔(气
   │░░░║ ║░░░║ ║░░░║ ║░░░║ ║░░░║ ║░░░║ ║░░░║ ║░░░║ ║░░░║ ║░░░│   动网络)
   │░░░╚═╝░░░╚═╝░░░╚═╝░░░╚═╝░░░╚═╝░░░╚═╝░░░╚═╝░░░╚═╝░░░╚═╝░░░│
   │██████████████████████████████████████████████████████████│ ← 底部抗
   └──────────────────────────────────────────────────────────┘   拉层(布)

   充气后（向下弯曲）:

   ┌─────┐ ← 充气口（开始膨胀）
   │█████│
   │░░╔══╗            
   │░░║ /
   │░░╚╗ ╗
    █████╗
       █████╗
          █████╗     ← 各气腔依次膨胀, 顶部伸长 > 底部
             █████╗     (类似活鳗鱼/毛毛虫弯曲)
                █████╗
                   ╚════╗
                       指尖向下，形成抓握动作
```

### 软体手指尺寸建议（DIY 参考）

| 参数 | 推荐值 | 备注 |
|---|---|---|
| 单指总长 | 90 mm | 略短于成人手指 |
| 气腔数量 | 8 ~ 10 | 决定弯曲均匀度 |
| 气腔间距 | 1.5 mm | 决定弯曲半径 |
| 气腔宽度 | 10 mm | |
| 气腔高度 | 8 mm | |
| 顶部壁厚 | 1.5 mm | 易膨胀 |
| 底部壁厚 | 2.5 mm | 抗拉伸 |
| 材料 | Ecoflex 00-30 硅胶 | 邵氏 00-30 度 |

---

## 六、UI 界面草图（800×480 LCD）

```
 ┌─────────────────────────────────────────────────────────────┐ 0,0
 │   医用气动辅助手套 - 控制系统          状态: GRIP            │   60
 ├─────────────────────────────────────────────────────────────┤
 │                                                             │
 │                          压力                               │
 │      ┌───────────┐    ┌──────────────────────┐  ┌────────┐ │
 │      │           │    │                      │  │        │ │ 
 │      │     +     │    │       45.0 kPa       │  │   -    │ │
 │      │           │    │                      │  │        │ │
 │      │  加压抓握 │    │  ▓▓▓▓▓▓▓░░░░░░░░░░░  │  │ 泄压松手│ │
 │      │           │    │  目标: 60 kPa        │  │        │ │
 │      └───────────┘    └──────────────────────┘  └────────┘ │
 │                                                             │
 │      档位: ▣▣▣▢▢            速度:▣▣▢                    │
 │                                                             │
 │                                                             │
 │                                                             │
 │   ╔═══════════════════════════════════════════════════╗     │
 │   ║   压力曲线 (kPa - 时间)                            ║     │
 │   ║                  ▁▂▃▄▆▆▇▇█▆▄                     ║     │
 │   ║                                                    ║     │
 │   ╚═══════════════════════════════════════════════════╝     │
 │                                                             │
 ├─────────────────────────────────────────────────────────────┤ 420
 │   [紧急停止]   [设置]  [校准]    版本 v0.1                  │   480
 └─────────────────────────────────────────────────────────────┘
   0                                                          800
```

### UI 控件尺寸（适合患者手指点按）

| 控件 | 位置 (x,y) | 尺寸 (w×h) | 颜色 |
|---|---|---|---|
| 加号 + | (50, 120) | 160×160 | 绿色 |
| 减号 − | (590, 120) | 160×160 | 橙色 |
| 压力显示 | (250, 130) | 300×140 | 白底黑字 |
| 紧急停止 | (50, 430) | 160×40 | 红色 |

---

## 七、台架联调现状 (2026-08-04 记录)

> 详细排障过程见演示视频 `简易版实验结果演示.mp4` 与各 README。

### 已验证 ✅
- 上电自检：未插传感器 2~3 秒内蜂鸣 + FSM 锁 EMERGENCY + LED0 常亮（故障检测按设计工作）
- 触摸链路：GT911 → PS EMIO 软件 IIC → 左右半屏充/泄请求，完好
- 仿真压力模式（`SIM_PRESSURE=1`）全链路：摸左屏充气 ~4s 到 50kPa 自停（GRIP→HOLD）、
  HOLD 泄漏回差自动补气、摸右屏阀开泄气 —— 气球演示成功
- 泵/阀真实动作：IRLZ44N 气泵低边驱动 + ULN2803 阀驱动均正常
- LCD 压力数值显示（"XXX.XX KPA"，5×7 字库放大 4 倍）工作正常

### 已排除的故障案例（备查）
- **Q1 (IRLZ44N) 栅氧击穿**：泵不转、G 极仅 0.9V、断电 G-S 电阻 150Ω（健康应 MΩ）。
  根因为 ESD（布面环境焊接）。换新管后在路 G-S 量到 97.5k（=100K 下拉并联值），泵恢复。
  教训：勿在布面焊接；新 MOSFET 先焊 S 极与 100K 下拉、最后焊 G 极串联电阻。
- **压力读数乱跳**：`pressure_iic.v` 未按官方规格书配置 Reg0xA5 / 未轮询 sco / 系数错误，
  已按官方 C 例程彻底重写（系数 1638 = ad/640 → 0.01kPa），比特级仿真全过。

### 遗留问题 ⏳（下次开机先确认）
1. **地弹负尖峰**：阀切换时 T19 量到 -2.5V ~ -3.85V（FPGA IO 耐压下限 -0.5V）。
   处方：12V 电路 GND ↔ ZYNQ ATK GND 并 2~3 根杜邦线。
2. **ULN2803 COM (pin10) 接 12V+ 待确认**（阀线圈续流回路，未接则关断向地打反峰）。
3. **XGZP6857D 需重买 IIC 数字版**（旧传感器疑似焊接烫死；勿买模拟版）。
   到手后：先 `SIM_PRESSURE=1` 确认 IIC 通信正常 → 读数正常后改 0 恢复闭环。

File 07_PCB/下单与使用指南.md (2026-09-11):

# 下单与使用指南（驱动板 PCB）

> 给第一次打板的你：照着做就行。这块板**已经过三重验证，电气连接与电路图完全一致**。

---

## 这个文件夹里有什么

| 文件 | 作用 | 你要用吗 |
|---|---|---|
| **医用手套驱动板.epro** | 立创EDA专业版工程（原理图+PCB） | ★ 主文件，用它打开/编辑/下单 |
| **医用手套驱动板_gerber.zip** | 打板生产文件（Gerber+钻孔） | ★ 不想开软件就直接传它下单 |
| 验证报告.md | 三重验证的结果 | 看一眼放心 |
| view_top.png / view_bot.png / sch_render.png | 顶层/底层/原理图 照片 | 目检 |
| gen_pcb.py 等 .py | 生成+验证用的脚本（我写的） | 不用管，想了解再看 |

---

## 路线 A（最简单，推荐）：直接用 Gerber 下单

我已经把生产文件打包好了，**不用开任何软件**：

1. 浏览器打开 嘉立创下单助手（`https://www.jlc.com` → 计价/下单）。
2. 上传 **`医用手套驱动板_gerber.zip`**。
3. 等它解析完，确认参数（一般保持默认即可）：
   - 层数 **2 层**、尺寸约 **90×68mm**
   - 板厚 **1.6mm**、阻焊颜色随你（常用绿色）
   - 铜厚 **1oz**、喷锡（有铅/无铅都行）
4. 数量 5 片（最低档），提交付款。几天后快递到手。

---

## 路线 B：在立创EDA专业版里打开 .epro（可查看/修改）

1. 打开你电脑里的 **立创EDA专业版**。
2. 菜单 **文件 → 打开 → 项目**（或"导入"），选中 **`医用手套驱动板.epro`**。
3. 打开后你会看到**原理图**和 **PCB** 两个标签页，就是我生成的那套。
4. **建议先点一次「设计规则检查(DRC)」**确认无误（工具 → 设计规则检查）。
   - 你会看到几条"silkscreen/丝印"类的提示，那是正常的（丝印压焊盘，出厂会自动裁掉），**没有短路/未连接就是好的**。
5. 想下单：在 PCB 页 **文件 → 导出 → PCB制板文件(Gerber)**，或直接点软件里的 **"去下单"** 按钮（立创EDA和嘉立创是打通的）。

> ⚠️ 如果你在软件里看到 GND 没铺铜：那是因为铺铜在导出时按 KiCad 方式重填过。在立创EDA里若想重铺，选中底层 → 右键 → 重建所有铺铜区即可（不影响 Gerber.zip，那份已经是铺好的）。

---

## 收到板子后怎么焊（全直插，只有 1 个小贴片）

**焊接顺序：先矮后高。**

1. **电阻** R1/R2(4.7K)、R3(100R)、R4(100K) — 轴向，不分正负。
2. **二极管** D1(1N5822)、D2(1N4007) — ⚠️ **有正负**：外壳有白圈的一端是**负极**，对照板上丝印/焊盘（负极朝 +12V，即朝 T1/T2 的 + 端）。
3. **IC 座 + ULN2803**(U2) — 先焊 18 脚 IC 座，芯片后插。⚠️ **缺口/圆点对 1 脚**（板上有 1 脚方焊盘）。
4. **瓷片电容** C2/C3(104) — 不分正负。
5. **电解电容** C1(100µF) — ⚠️ **长脚=正极**，插方焊盘（+ 端，朝 +12V）。
6. **AMS1117**(U1) — 唯一的贴片(SOT-223)，也最好焊：先焊一边固定，再焊其余脚和大散热片。
7. **IRLZ44N**(Q1) — TO-220 三脚，⚠️ 别插反（G/D/S 对照板上 1 脚方焊盘）。
8. **接线端子** T1/T2/T3(KF301) — 蓝绿色那种，注意方向（进线口朝板外）。
9. **排针/排母** J1(6P)、J2(4P) — 接杜邦线到 ZYNQ / 接传感器。

**接线（和你原电路图一致）：**
- T1 ←→ 气泵（+ : −）
- T2 ←→ V2 阀（+ : −）
- T3 ←→ 12V/3A 适配器（+ : −，经 DC 母座转接线）
- J1(6P) ←→ ZYNQ ATK 口 6 根杜邦线：**1=SCL 2=SDA 3=泵 4=阀 5=GND 6=+5V**
- J2(4P) ←→ 气压传感器：**VCC / GND / SCL / SDA**（对照你传感器模块的针脚顺序）

---

## 上电顺序（安全！和原方案一样）

1. **只接 ZYNQ + 驱动板**（不接 12V）：LCD 跑起来，看 Gate/OUT1 电平是否随状态机翻转。
2. **接 12V 空载**（不接泵/阀）：量 T1/T2 输出端电压对不对。
3. **接泵和阀**联调：做 充气→保压→泄气 全流程。
4. ⚠️ **调试期严禁戴在人手上**；V2 必须是**常开(NO)**型，断电自动泄压。

---

## 万一想改板子

板子是由 `gen_pcb.py` 自动生成的（元件布局、走线都在里面，带中文注释）。
改完重新跑一遍就行（需要装好 Python + KiCad）：

```
py gen_pcb.py            # 重新生成 .epro
< KiCad python > convert_epro.py 医用手套驱动板.epro board.kicad_pcb
kicad-cli pcb drc ...    # 重新验证
```

不懂代码也没关系——直接在立创EDA专业版里打开 .epro 手动改更简单。

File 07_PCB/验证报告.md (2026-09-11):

# 驱动板 PCB 验证报告

> 项目： 医用气动辅助手套 · 驱动板（替代洞洞板）
> 生成： `gen_pcb.py` → `医用手套驱动板.epro`（立创EDA专业版工程）
> 日期： 2026-07-30 · 验证工具： KiCad 10.0.5（后台） + 自写核对脚本

---

## 一句话结论

**这块板子的电气连接与你的电路图 100% 一致，可以放心打板。**
三项互相独立的验证全部通过，无任何短路 / 漏连 / 间距错误。

---

## 三重独立验证（怎么确认"对不对"）

### ① 网络表逐脚核对 —— 最核心，防"连错线"
用脚本把 PCB 里**每一个焊盘实际连到哪个网络**读出来，和根据你
《最终元件清单_2026-07-21》+ `gen_final_circuit.py` **手工逐条写出的权威网络表**双向比对：

```
[OK] +12V      8脚  T3.1 T1.1 T2.1 U2.10 D1.2 D2.2 C1.1 C2.1
[OK] +5V       4脚  J1.6 U1.3 J2.1 C3.1
[OK] +3.3V     4脚  U1.2 U1.4 R1.1 R2.1
[OK] GND      10脚  J1.5 U1.1 J2.2 R4.2 Q1.3 U2.9 C1.2 C2.2 C3.2 T3.2
[OK] SCL       3脚  J1.1 R1.2 J2.3
[OK] SDA       3脚  J1.2 R2.2 J2.4
[OK] PUMP      2脚  J1.3 R3.1
[OK] GATE      3脚  R3.2 R4.1 Q1.1
[OK] VALVE     2脚  J1.4 U2.1
[OK] PUMP_D    3脚  Q1.2 D1.1 T1.2
[OK] VALVE_OUT 3脚  U2.18 D2.1 T2.2
[OK] <无网络>  14脚悬空 (U2 未用的 IN2~8/OUT2~8, 符合设计)
```
**全部通过 ✔**（连最容易错的 ULN2803「OUT1=第18脚」也正确）

### ② KiCad 真实工具导入 + DRC 规则检查 —— 防"工艺不达标"
- `.epro` 能被 KiCad 的 EasyEDA Pro 导入器**正常打开**（证明文件没坏、格式正确）。
- DRC（设计规则检查）：**短路 0 · 未连接 0 · 间距违规 0**。
- 仅余 3 类**无害提示**，不影响打板：
  - `lib_footprint_issues`×17：只是"封装库未登记进 KiCad 配置"的提示，封装其实已内嵌在板里且正确，任何 EasyEDA 导入的板都会有这条。
  - `silk_over_copper`×3 / `silk_overlap`×3：个别丝印压在焊盘边缘（C1 电容圆框、T3 端子框）。嘉立创生产时会自动裁掉压焊盘的丝印，不影响功能。
  - `starved_thermal`×1：J1.5 到地平面只有 1 根热焊辐条，但它**另有 GND 走线直连**，电气上完全导通。

### ③ 渲染图人工目检 —— 防"看着不对"
- `view_top.png`（顶层铜）：+12V 宽线从 T3 进，沿顶边和右边分到各负载，ULN2803 居中，布局清爽。
- `view_bot.png`（底层铜）：**整面 GND 铺铜**，热焊盘连接正常。
- `sch_render.png`（原理图）：17 个元件每个引脚的网络标注都与设计一致。

---

## 板子规格

| 项 | 值 |
|---|---|
| 尺寸 / 层数 | 90 × 68 mm · 双面(2层) |
| 最小线宽 / 间距 | 0.4 mm / 0.3 mm（远高于嘉立创免费线 0.127mm） |
| +12V 动力线宽 | 2.5 mm（泵电流余量足） |
| 地 | 底层整面铺铜 + 顶层 GND 走线 |
| 过孔 / 钻孔 | 过孔 8 个 · 最小孔 0.8 mm |
| 封装 | 全部直插(TO-220/DIP-18/DO-41/轴向/KF301/2.54排针)，仅 AMS1117 是 SOT-223 小贴片 |

---

## 关键设计要点（与你的电路图对应）

- **泵通道**：T19→J1.3(PUMP)→R3(100R)→Q1 栅极；R4(100K) 栅极下拉→GND，上电默认关泵；Q1 源→GND，漏→泵−。
- **阀通道**：J15→J1.4(VALVE)→U2 IN1；U2 OUT1(18脚)→阀−；COM(10脚)→+12V；GND(9脚)→GND；IN2~8 悬空。
- **续流**：D1(1N5822) 并在泵、D2(1N4007) 并在阀，阴极都朝 +12V。
- **电源**：T3 进 12V；U1(AMS1117) 从 +5V 降 3.3V 只供 R1/R2 上拉；C1/C2 并在 12V/GND，C3 并在传感器 VCC/GND。
- **共地**：GND 轨与 ZYNQ（J1.5）共地，12V 不进 ZYNQ。

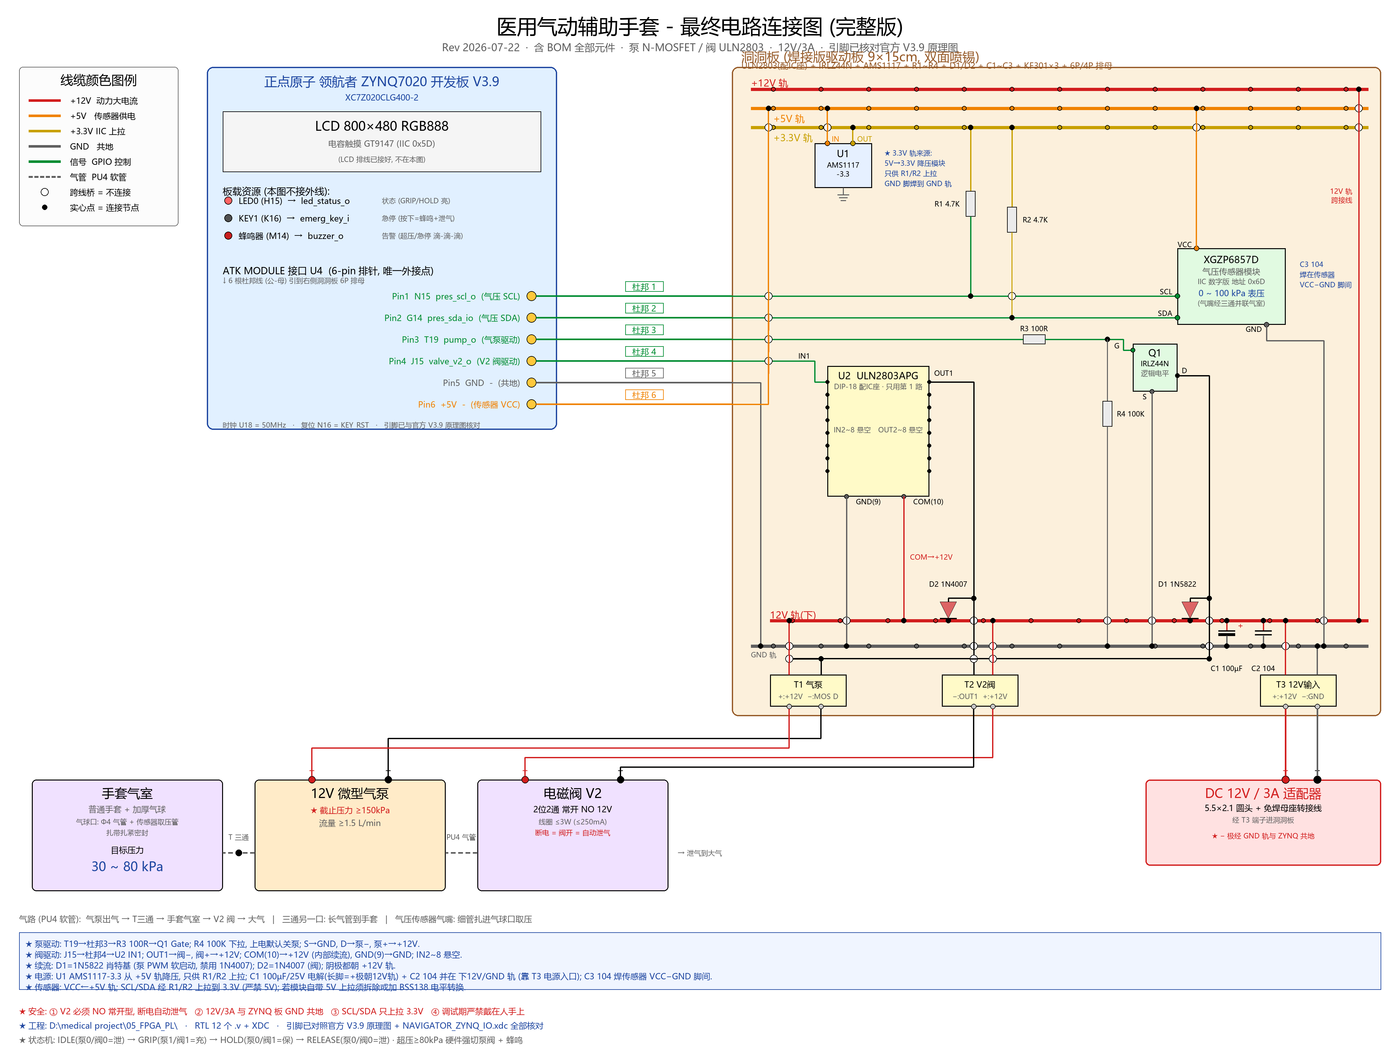
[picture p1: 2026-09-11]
最终电路图.png

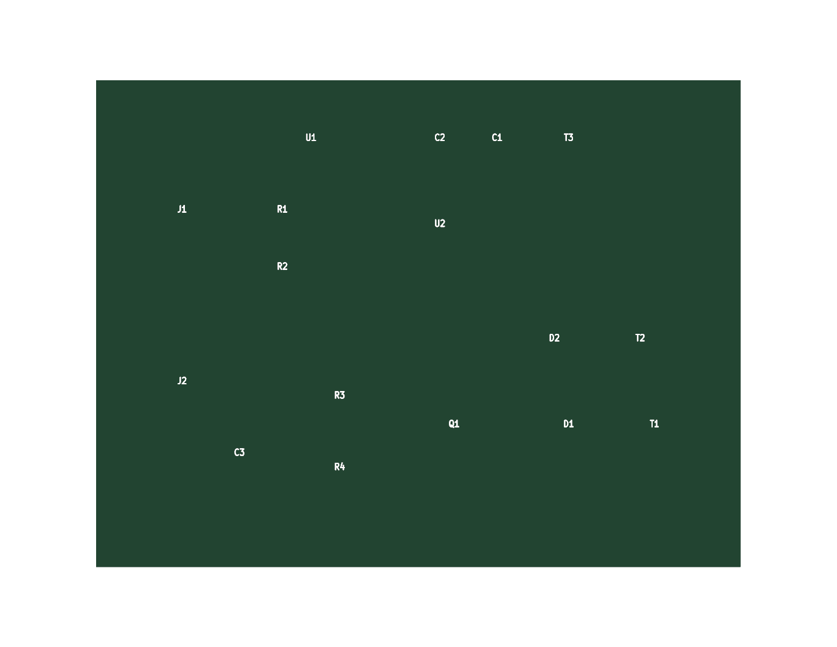
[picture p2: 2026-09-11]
07_PCB/render_top.png

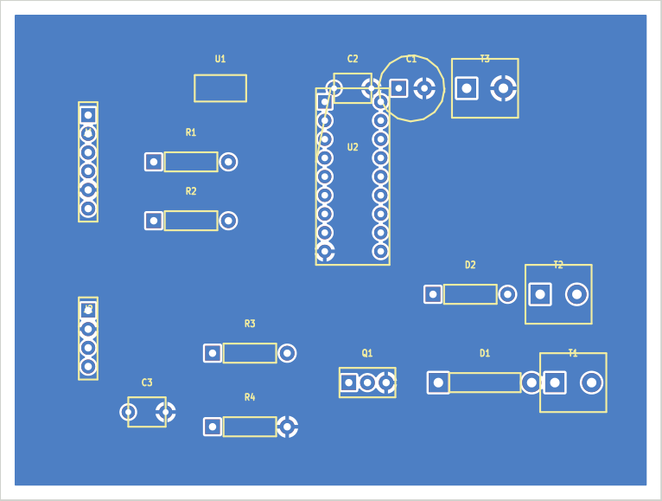
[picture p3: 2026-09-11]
07_PCB/board2d.png

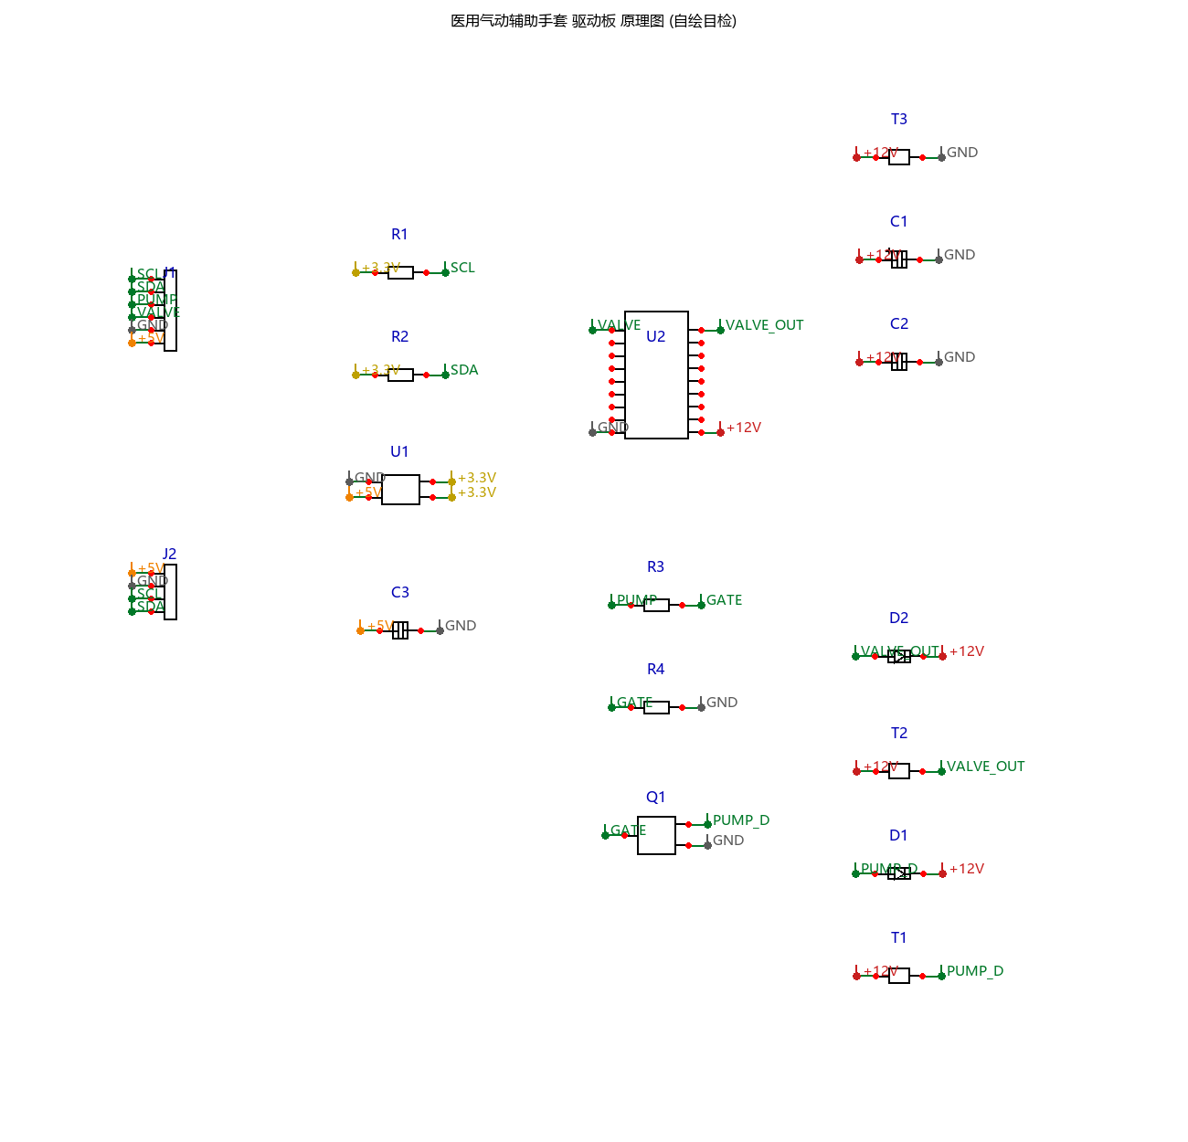
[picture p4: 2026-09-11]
07_PCB/sch_render.png

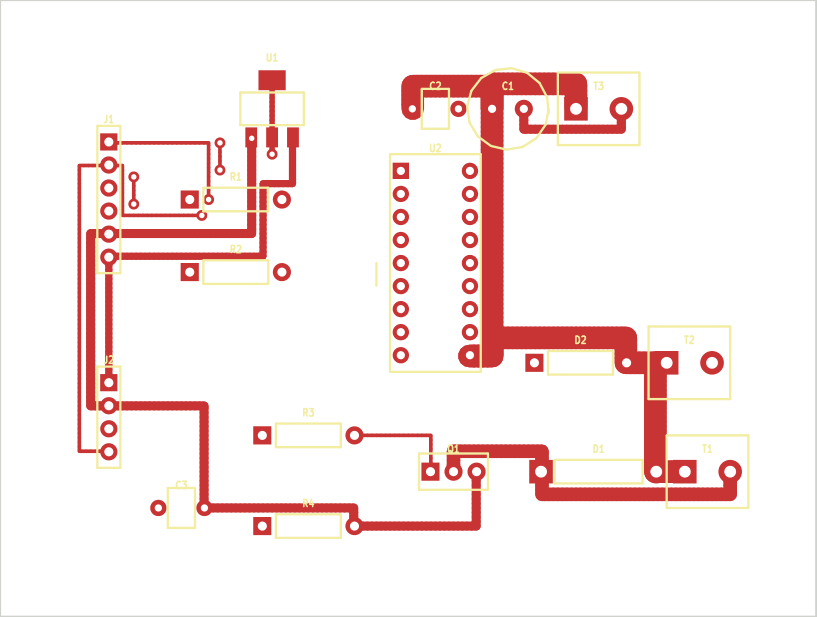
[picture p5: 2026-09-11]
07_PCB/view_top.png

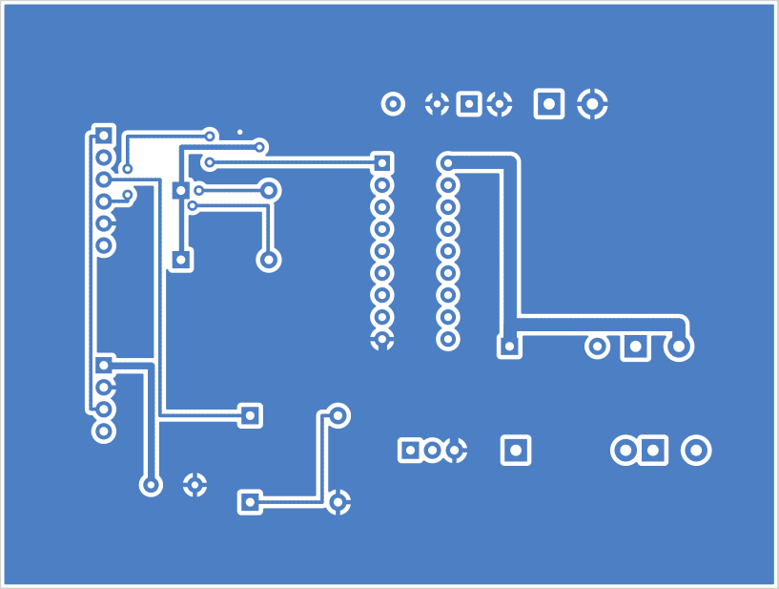
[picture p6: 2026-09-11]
07_PCB/view_bot.png

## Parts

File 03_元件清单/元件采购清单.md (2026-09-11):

# 医用气动辅助手套 - 元件采购清单（精简版）

> 单一最实惠方案，总预算 **¥200 ~ ¥350**
> 编制日期：2026-05-11
> 修订：2026-05-13（★ 砍 V1 充气阀，蜂鸣器改用板载 M14，ULN2803 焊到洞洞板）
> 修订：2026-08-16（★ 驱动板已 PCB 化打板；气压传感器需重买 IIC 数字版）
>
> 📌 **权威 BOM 以同目录 `最终元件清单_2026-07-21.md/.png` 为准**（逐元件核对过最终电路图）；
> 淘宝搜索关键词见 `淘宝直搜词清单_2026-07-22.md/.png`。

---

## 方案变更说明（必读）

| 项 | 原方案 | 新方案 | 理由 |
|---|---|---|---|
| V1 充气阀 | NC 常闭电磁阀 ×1 | ★ **砍掉** | 板上 GPIO 不够走 6 信号；V2 NO 已能 fail-safe |
| 状态蜂鸣器 | 外购 5V 有源 | ★ **改用板载 M14** | 领航者板上自带,Verilog 直接驱动 |
| 驱动板 | 洞洞板焊接 | ★ **正式 PCB (2026-07-30)** | 立创EDA 工程 `07_PCB/医用手套驱动板.epro` + Gerber 打板包；洞洞板原型已台架验证 |
| 气压传感器 | XGZP6857D | ★ **需重买, 认准 IIC 数字版** | 旧传感器疑似焊接烫死(2026-08-04); 勿买模拟输出版 |
| 信号引出 | 全走 ATK MODULE U4 排针 + 杜邦线 | 同 | 不拆开发板外壳,4 GPIO + 5V + GND 一根 6 芯排线引出 |

---

## 已有设备（无需购买）

| 设备 | 说明 |
|---|---|
| 正点原子 领航者 ZYNQ7020 开发板 | XC7Z020CLG400-2 |
| 7" 800×480 RGB 触摸 LCD | 配套触摸控制器 GT911 (★ 实为 GT911 非 GT9147, 05-21 实测确认) |
| PC + Vivado / Vitis 2020.2 | 开发工具链 |

---

## 必购清单

### 1. 气动元件

| 元件 | 规格 | 数量 | 参考价 | 购买关键词 |
|---|---|---|---|---|
| 微型气泵 | DC 12V, ≥100kPa, ≥1.5L/min | 1 | ¥30~50 | "微型气泵 12V 100kPa" |
| ~~电磁阀 V1（充气）~~ | ~~2位3通 NC 12V M5~~ | ~~1~~ | ~~¥15~25~~ | ★ **已砍, 不买** |
| 电磁阀 V2（泄气） | 2位2通 直动式 **常开 NO** 12V M5 | 1 | ¥15~25 | "2位2通 电磁阀 12V 常开" |
| 气压传感器 | **XGZP6857D** IIC **数字版** 0~100kPa | 1 | ¥25~40 | "XGZP6857D 气压传感器" ★ 认准 IIC 数字输出, 勿买模拟电压版 |
| PU 气管 + 接头套装 | Φ4×Φ2.5，含快插接头、三通 | 1套 | ¥15~25 | "PU气管4mm 套装" (砍 V1 后用量减少) |

> ⚠️ V2 泄气阀必须是 **常开型 NO**（断电自动泄压），买错有危险！
> 💡 砍 V1 后气路简化为: 气泵 → 手套气室 → V2 → 大气, 三通只需 1 个 (并联气压传感器)

### 2. 驱动与电源

| 元件 | 规格 | 数量 | 参考价 | 购买关键词 |
|---|---|---|---|---|
| V2 阀驱动芯片 | ULN2803APG DIP-18 | 1 | ¥3 | "ULN2803" (只驱动 V2 阀, 不再直接驱动气泵) |
| 气泵驱动 MOSFET | 逻辑电平 N-MOSFET, TO-220 优先, ≥30V/≥10A, 如 IRLZ44N/IRLZ34N | 1 | ¥3~8 | "逻辑电平 N MOSFET IRLZ44N" |
| 栅极电阻 | 100 Ω 1/4W | 1 | ¥0.5 | "100R 电阻" (串在 T19 与 MOSFET Gate 之间) |
| 栅极下拉电阻 | 100K Ω 1/4W | 1 | ¥0.5 | "100K 电阻" (Gate 到 GND, 上电默认关泵) |
| 续流二极管 | 1N4007 或 SS14/1N5819 | ★ **2** | ¥1 | "1N4007" / "SS14" (一颗给气泵, 一颗给 V2) |
| 12V/3A 适配器 | DC 5.5×2.1 | 1 | ¥20~30 | "12V 3A 电源适配器" |
| 上拉电阻 | 4.7K Ω 1/4W | 2 | ¥0.5 | "4.7K 电阻" (气压 IIC 上拉到 3.3V, 不能上拉到 5V) |
| ~~DC-DC 降压模块~~ | ~~12V→5V/3.3V~~ | ~~1~2~~ | ~~¥5~10~~ | 砍掉, +5V 从 ATK MODULE Pin6 取 |
| 3.3V LDO | AMS1117-3.3 或 XC6206 | 1 | ¥1 | "AMS1117-3.3" (给 IIC 上拉提供确定的 3.3V) |
| IIC 电平转换模块 | BSS138 双向 2 路 IIC 电平转换 | 0~1 | ¥2 | "I2C 电平转换 BSS138" (若 XGZP6857D 模块自带 5V 上拉则必须加) |
| 去耦电容 | 0.1uF (104) + 47uF~220uF 电解 | 1组 | ¥1~3 | "104 电容 100uF 电解" (ULN2803/传感器/12V 动力退耦) |

### 3. 手套与附件

| 元件 | 规格 | 数量 | 参考价 | 购买关键词 |
|---|---|---|---|---|
| 普通手套 | 棉线/橡胶/乳胶手套，有弹性即可 | 1双 | ¥20~30 | "乳胶手套 加厚" / "棉线手套" |
| 气球 / 橡胶指套 | 套在手套手指上作为气室 | 1包 | ¥5~10 | "气球 加厚" / "橡胶手指套" |
| **PCB 打板** | ★ 正式方案: 立创EDA 打板 (2层 90×68mm 全直插), 用 `07_PCB/医用手套驱动板_gerber.zip` 直接下单, 每月有免费打板券 | 1 | ¥0~20 | 立创商城/嘉立创打板 |
| ~~洞洞板~~ | ~~9×15cm 双面~~ | ~~1~~ | ~~¥3~~ | ★ 原型验证已完成, 正式版用 PCB；若手焊原型仍需 1 块 |
| 杜邦线 | 公-母 40P (★ 接 ATK MODULE 排针 → 驱动板) | 1包 | ¥10 | "杜邦线 公母 40P" |
| IC 座 | 18-pin DIP 圆孔 (★ 给 ULN2803 用,免直焊芯片) | 1 | ¥1 | "18脚 IC座 DIP" |
| 螺丝端子 | KF301 2P 蓝色 (★ 3 个, 给气泵、V2、12V 输入) | 3 | ¥3 | "KF301-2P 接线端子" |
| ~~蜂鸣器~~ | ~~5V 有源~~ | ~~1~~ | ~~¥1~~ | ★ **不用买, 领航者板载 M14 已自带** |
| 急停按钮 | 自锁红钮 (可选) | 0~1 | ¥8~12 | 调试期可用板载 KEY1 代替 |
| 扎带 / 热缩管 | - | 1包 | ¥5 | "扎带" / "热缩管" |

> 💡 手套方案：普通手套 + 气球/橡胶指套做气室，成本低、易更换，验证原理完全够用。
> 💡 蜂鸣器告警逻辑(超压 OR 急停 → 2Hz 滴-滴-滴)已写进 PL 端 `buzzer_ctrl.v`, 接到板载 M14, **无需外接**。

---

## 一键采购清单

```
气动部分
  微型气泵 12V 100kPa              x1  ¥40
  2位2通常开电磁阀 12V M5          x1  ¥20
  XGZP6857D 气压传感器 IIC         x1  ¥30
  Φ4 PU气管 + 快插接头套装         x1  ¥20

电气部分 (焊接洞洞板版)
  ULN2803 + 18脚 IC 座                 ¥4
  逻辑电平 N-MOSFET + 100R + 100K      ¥6
  1N4007/SS14 二极管 x2                ¥1
  4.7K 上拉电阻 x2 + AMS1117-3.3       ¥2
  BSS138 IIC 电平转换模块(备用)        ¥2
  12V/3A 电源适配器                x1  ¥25
  洞洞板 9x15 + KF301-2P 端子 x3 + 公母杜邦线 x1包  ¥20

手套与结构
  普通乳胶手套 / 棉线手套          x1  ¥25
  加厚气球 / 橡胶指套              x1  ¥8
  扎带、热缩管等                       ¥5
─────────────────────────────────────
                       总计 ≈ ¥210
```

**浮动区间：¥200 ~ ¥350**（取决于店铺、MOSFET 封装和是否买备用件）

★ 保留砍 V1 + 板载蜂鸣器 + 砍 DC-DC 降压模块；新增 MOSFET 和 12V/3A 电源是为了提高气泵通道余量。

---

## 购买渠道

| 平台 | 适合品类 | 优势 |
|---|---|---|
| **淘宝** | 气泵、阀、气管、手套 | 品类全、个人友好 |
| **立创商城** | ULN2803、电阻电容 | 正品、资料齐 |
| **1688** | 批量采购 | 更便宜（量大有优势） |

---

## 采购顺序

```
第一批：驱动板 (已完成, 2026-07/08)
  └─ ★ 正式 PCB 已用 Gerber 打板 (07_PCB/医用手套驱动板_gerber.zip)
   → 元件按 PCB 丝印插焊: IRLZ44N + ULN2803 + 1N4007×2 + 电阻 + KF301 端子
   → 洞洞板原型已台架验证 (2026-08-04); 注意 MOSFET 防静电, 勿在布面焊接

第二批：气动联调 (已完成, 仿真压力模式气球演示成功)
  └─ 气泵、V2 电磁阀、PU 气管 (¥110)
   → 做"摸左屏 → 充气 → 保压 → 摸右屏泄气"流程, 屏幕能看到压力变化

第三批：恢复真实闭环 (⏳ 当前待办)
  └─ 重买 XGZP6857D IIC **数字版** (¥30)
   → 先 SIM_PRESSURE=1 确认 IIC 通信正常, 再改 0 恢复真实压力闭环

第四批：上手套
  └─ 普通手套 + 气球指套 (¥35)
   → 完整系统测试，调试期不要戴在人手上！
```

---

## 注意事项

1. **气泵流量** ≥ 1.5 L/min，避免买到只能打气球的玩具泵
2. **气泵驱动** 不再建议走 ULN2803 单通道，统一用逻辑电平 N-MOSFET 低边驱动；ULN2803 只驱动 V2 阀。
3. **泄气阀必须是常开 NO**，断电自动泄压，这是安全底线
4. **接口统一 Φ4 气管 + M5 螺纹**，配件通用不混乱
5. **传感器装靠近手指端**，反馈最真实
6. **IIC 上拉电源**：ZYNQ GPIO 是 3.3V 电平，SCL/SDA 上拉必须接 3.3V（不能接 5V！）。若 XGZP6857D 模块自带 5V 上拉，必须拆除 5V 上拉或加 BSS138 双向电平转换。
7. **12V 适配器功率**：直接选 12V/3A，避免气泵启动电流 + V2 阀同时工作时压降复位。
8. **调试期不要戴在人手上**，先拿瓶罐做负载测试。
9. **PCB 焊接顺序**: 先矮后高 (电阻→二极管→IC 座→端子→MOSFET)；**MOSFET 最后焊且先焊 S 极**, 焊接前摸接地金属放电, 勿在布面/床单环境操作 (08-04 曾 ESD 击穿 IRLZ44N 栅氧)。洞洞板原型布局备查: 4 条电源轨横向走 (+3.3V/+5V/+12V/GND), MOSFET 靠近气泵端子, ULN2803 靠近 V2 端子, 续流二极管阴极朝 +12V。
10. **不要拉 12V 进 ZYNQ 板**: 12V 只进洞洞板动力轨；ZYNQ 只接 T19/J15/N15/G14/+5V/GND，其中 GND 与 12V- 共地。
11. **板载蜂鸣器**: 不用买, M14 由 buzzer_ctrl.v 驱动, 超压或急停时 2Hz 间歇响。

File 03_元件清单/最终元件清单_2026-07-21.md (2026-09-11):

# 医用气动辅助手套 - 最终元件采购清单

> **Rev 2026-07-21 终审版** — 已对照 RTL 代码、XDC 约束、官方 V3.9 原理图逐项核对
> 配套电路图： `D:\medical project\电路连接图.png` (Rev 2026-07-21)
> 总预算： **¥220 ~ ¥360**

---

## 本次修订记录 (vs 2026-05-13 版)

| # | 项 | 旧 | 新 | 原因 |
|---|----|----|----|---|
| 1 | 泵续流二极管 D1 | 1N4007 任选 | **1N5822 肖特基 (必选)** | RTL 中 pump_o 是 PWM 软启动(~390kHz), 1N4007 是工频慢管, 会发热 |
| 2 | 气泵压力规格 | 最大 ≥100kPa | **最大 ≥150kPa** | "最大压力"= 截止压力(流量=0); 要打到 80kPa 需留裕量 |
| 3 | 电磁阀 V2 | 常开 NO 12V | 常开 NO 12V + **线圈 ≤3W** | ULN2803 在 3.3V 输入下保证驱动 300mA, 阀电流须 ≤250mA |
| 4 | MOSFET | IRLZ44N/IRLZ34N 二选一 | **确定 IRLZ44N** | 最好买, TO-220 直插, 逻辑电平 |
| 5 | 12V 电源转接 | 未列 | **DC5.5×2.1 免焊母座转接线** | 适配器圆头 → KF301 端子, 不用剪线 |
| 6 | 电路图 | 漏画 AMS1117、3 处穿线 | 已全部修正重绘 | 见 电路连接图.png |

---

## 一、已有设备 (无需购买)

| 设备 | 说明 |
|---|---|
| 正点原子 领航者 ZYNQ7020 开发板 V3.9 | XC7Z020CLG400-2 |
| 7" 800×480 RGB 电容触摸 LCD | GT9147, 排线已接好 |
| PC + Vivado / Vitis 2020.2 | 开发工具链 |
| 板载资源 (LED0/KEY1/蜂鸣器) | H15 / K16 / M14, 全部走 PL 端, 不外接 |

---

## 二、必购清单

### 1. 气动元件

| 元件 | 规格 (★ 关键) | 数量 | 参考价 | 购买关键词 |
|---|---|---|---|---|
| 微型气泵 | DC 12V, ★ **最大压力 ≥150kPa**, 流量 ≥1.5L/min | 1 | ¥35~60 | "微型气泵 12V 高压 150kPa" / "12V 活塞气泵" |
| 电磁阀 V2 (泄气) | 2位2通 直动式 ★ **常开 NO**, DC 12V, ★ **线圈 ≤3W (电流 ≤250mA, 电阻 ≥48Ω)**, M5/Φ4 接口 | 1 | ¥15~25 | "2位2通 电磁阀 12V 常开" |
| 气压传感器 | ★ **XGZP6857D IIC 数字版** (地址 0x6D), 0~100kPa 表压 | 1 | ¥25~40 | "XGZP6857D 气压传感器 I2C" |
| PU 气管套装 | Φ4×Φ2.5, 含快插接头 + ★ **T 三通 ×1** | 1套 | ¥15~25 | "PU气管 4mm 套装 三通" |

> ⚠️ **V2 必须常开 NO** (断电自动泄压), 买错有危险！下单前问客服确认"断电通气"。
> ⚠️ 传感器必须买 **IIC 数字版**, 同型号有模拟电压版, 买错无法通信。
> 💡 阀到货后用万用表量线圈电阻: ≥48Ω 即合格 (=12V/250mA)。

### 2. 驱动与电源 (洞洞板部分)

| 元件 | 规格 | 数量 | 参考价 | 备注 |
|---|---|---|---|---|
| N-MOSFET Q1 | ★ **IRLZ44N** TO-220 逻辑电平 | 1 | ¥3~5 | 泵低边驱动; 备用型号 IRLB8721/FQP30N06L |
| 达林顿阵列 U2 | ULN2803APG DIP-18 | 1 | ¥3 | 只驱动 V2 阀; COM(10脚) 接 +12V |
| IC 座 | 18-pin DIP 圆孔 | 1 | ¥1 | ULN2803 免直焊 |
| 续流二极管 D1 | ★ **1N5822 肖特基** (3A/40V 直插) | 1 | ¥0.5 | 泵用, 必须肖特基/快恢复 |
| 续流二极管 D2 | 1N4007 | 1 | ¥0.2 | 阀用 (开关量即可) |
| 栅极串联电阻 R3 | 100 Ω 1/4W | 1 | ¥0.1 | T19 → Q1 Gate |
| 栅极下拉电阻 R4 | 100 KΩ 1/4W | 1 | ¥0.1 | Gate → GND, 上电默认关泵 |
| 上拉电阻 R1/R2 | 4.7 KΩ 1/4W | 2 | ¥0.2 | IIC 上拉到 ★ **3.3V** (严禁 5V) |
| 3.3V 稳压 U1 | AMS1117-3.3 (模块或 TO-223) | 1 | ¥1 | 从 +5V 轨降压出 3.3V 轨 |
| 去耦电容 | 100µF 电解 ×1 + 0.1µF(104) ×2 | 1组 | ¥1 | 12V 轨 / 5V 轨退耦 |
| 12V 电源适配器 | ★ **12V/3A**, DC 5.5×2.1 圆头 | 1 | ¥20~30 | 泵+阀动力 |
| DC 转接线 | ★ DC5.5×2.1 免焊母座 → 2 线 (红+/黑−) | 1 | ¥3 | 适配器 → T3 端子, 免剪线 |
| (备用) IIC 电平转换 | BSS138 双向 2 路 | 0~1 | ¥2 | 仅当传感器模块自带 5V 上拉且无法拆除时用 |

### 3. 结构件

| 元件 | 规格 | 数量 | 参考价 | 备注 |
|---|---|---|---|---|
| 洞洞板 | 9×15cm 双面喷锡 | 1 | ¥3 | 全部元件焊这块 |
| 接线端子 | KF301-2P 蓝色 | ★ **3** | ¥3 | T1 气泵 / T2 V2 / T3 12V输入 |
| 杜邦线 | 公-母 40P | 1排 | ¥10 | ATK U4 排针(公) → 洞洞板, 用 6 根 |
| 排针/排母 | 2.54mm 单排 | 1条 | ¥2 | 洞洞板上做杜邦插座与传感器插座 |
| 手套 | 棉线/乳胶手套 | 1双 | ¥20~30 | 气室外层 |
| 气球/橡胶指套 | 加厚 | 1包 | ¥5~10 | 手指气室 |
| 扎带/热缩管 | - | 1包 | ¥5 | 固定与绝缘 |
| 急停按钮 (可选) | 自锁红钮 | 0~1 | ¥8~12 | 调试期用板载 KEY1(K16) 即可 |

---

## 三、一键下单文本 (直接复制搜索)

```
微型气泵 12V 150kPa 高压 1.5L           ×1   ¥40
2位2通 常开电磁阀 12V (线圈≤3W)         ×1   ¥20
XGZP6857D 气压传感器 I2C 0-100kPa       ×1   ¥30
PU气管 4mm 套装 含三通                  ×1   ¥20
IRLZ44N 场效应管 TO-220                 ×1   ¥4
ULN2803APG DIP-18 + 18脚IC座            ×1   ¥4
1N5822 肖特基二极管                     ×1   ¥1 (买5个)
1N4007 二极管                           ×1   ¥1 (买10个)
直插电阻包 (100R/100K/4.7K 各若干)      ×1   ¥3
AMS1117-3.3 稳压                        ×1   ¥1
电解电容 100uF/25V + 瓷片 104           ×1组 ¥2
12V 3A 电源适配器 5.5*2.1               ×1   ¥25
DC5.5*2.1 免焊母座转接线                ×1   ¥3
KF301-2P 接线端子                       ×3   ¥3
洞洞板 9x15 双面                        ×1   ¥3
杜邦线 公对母 40P                       ×1排 ¥10
单排针排母 2.54                         ×1   ¥2
乳胶手套 + 加厚气球                     ×1组 ¥35
扎带热缩管                              ×1   ¥5
────────────────────────────────────────
合计 ≈ ¥215 (不含邮费, 浮动 ¥220~360)
```

---

## 四、焊接与接线要点 (与电路图对应)

1. **洞洞板电源轨**: 上排 +12V/+5V/+3.3V, 下排 +12V/GND; 上下 +12V 轨在板边用粗线跨接。
2. **3.3V 轨来源**: AMS1117-3.3, IN←+5V 轨, OUT→+3.3V 轨, GND→GND 轨; 只供 R1/R2。
3. **泵通道**: T19 → R3(100R) → Q1 Gate; R4(100K) Gate→GND; Q1 Source→GND 轨, Drain→T1−; 泵+ →T1+→+12V。
4. **阀通道**: J15 → U2 IN1; U2 OUT1→T2−; COM(10脚)→+12V; GND(9脚)→GND; IN2~8 悬空; 阀+ →T2+→+12V。
5. **续流二极管**: D1(1N5822) 并在 T1 两端, 阴极朝 +12V; D2(1N4007) 并在 T2 两端, 阴极朝 +12V。
6. **传感器**: VCC←+5V 轨, GND←GND 轨, SCL←杜邦1(N15)+R1 上拉 3.3V, SDA←杜邦2(G14)+R2 上拉 3.3V。
7. **12V 输入**: 适配器 → DC 免焊母座 → T3 (+→+12V 轨, −→GND 轨); ★ GND 轨已与 ATK Pin5(杜邦5) 相连 = 与 ZYNQ 共地。
8. **去耦电容**: 100µF 电解 + 104 ×1 并在下 +12V 轨与 GND 轨间 (靠 T3 入口, 电解长脚=正极朝 +12V); 另一只 104 直接焊在传感器排母 VCC−GND 脚间。
9. **12V 严禁进 ZYNQ 板**: ZYNQ 只接 杜邦1~4 信号 + Pin5 GND + Pin6 +5V。
10. 上电顺序: 先只接 ZYNQ+洞洞板测 Gate/OUT1 电平翻转 → 再接 12V 空载测 → 最后接泵阀。

---

## 五、采购顺序

```
第一批 (验证电路, ¥~70): IRLZ44N/ULN2803/IC座/电阻/二极管/AMS1117/电容
                        洞洞板/端子/杜邦线/排针排母/12V电源/DC转接线
  → 焊好空载测: 杜邦3 拉高 → Q1 Drain 应拉到近 0V; 杜邦4 拉高 → OUT1 拉到 ~1V
第二批 (气动联调, ¥~110): 气泵/V2阀/传感器/气管
  → LCD 上能看到压力读数, 做 充气→保压→泄气 全流程
第三批 (上手套, ¥~35): 手套/气球
  → 瓶罐负载验证 OK 后再考虑上手, 调试期严禁戴人手
```

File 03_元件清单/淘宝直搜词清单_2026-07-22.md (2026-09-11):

# 淘宝直搜词清单 — 医用气动辅助手套

> **Rev 2026-07-22** — 配套《最终元件清单_2026-07-21.md》使用
> 用法：每行"直搜词"整段复制 → 淘宝搜索框粘贴 → 按"筛选要点"挑 → 拿不准就问客服那句话
> 店铺说明：电子元件建议在大店一站购齐（省邮费）：**telesky旗舰店 / 优信电子 / risym旗舰店 / 佐田** 任选销量高评价好的；气动件在专业气动店买。

---

## 一、气动元件（4 样，最容易买错，逐个核对）

### 1. 微型气泵 ⚠️ 最关键参数：截止压力 ≥150kPa
- **直搜词**：`微型气泵 12V 高压 活塞式 150kPa`
- **备选词**：`12V 活塞气泵 打气泵 大压力`、`微型真空泵 12V 正压`
- **筛选要点**：
  - 参数页找"**最大压力 / 截止压力 ≥ 150kPa**"（≈1.5kg/cm² ≈ 0.15MPa）
  - 流量 ≥ 1.5L/min；电压 DC 12V
  - 出气嘴要能插 Φ4 气管（或送转接头）
  - ❌ 别买"555 气泵""鱼缸增氧泵"——压力只有 20~40kPa，打不到 80kPa
- **必问客服**："这款截止压力多少？能持续打到 80kPa 以上吗？"
- **参考价**：¥35~60

### 2. 电磁阀 V2 ⚠️ 买错有危险：必须"常开 NO"
- **直搜词**：`2位2通 电磁阀 12V 常开 直动式`
- **备选词**：`2V025-08 常开 12V`（亚德客型常见型号）、`微型电磁阀 常开 泄气阀 12V`
- **筛选要点**：
  - **常开 NO（Normally Open）**——商品名里必须带"常开"二字
  - 线圈 **DC 12V、功率 ≤3W**（电流 ≤250mA，线圈电阻 ≥48Ω）
  - 接口 M5 或 Φ4 快插
  - 品牌可选亚德客（AirTAC）官方店，质量稳；杂牌也行但先量电阻
- **必问客服**："**断电状态下两个气口是通的吗？**线圈功率多少瓦？"
- **到货自检**：万用表量线圈两脚电阻，≥48Ω 合格
- **参考价**：¥15~25

### 3. 气压传感器 XGZP6857D ⚠️ 必须 I2C 数字版
- **直搜词**：`XGZP6857D 气压传感器 I2C 模块`
- **备选词**：`XGZP6857D 100kPa 数字 压力传感器`
- **筛选要点**：
  - 同型号分 **I2C 数字版** 和 **模拟电压版**——只买 I2C 版！
  - 量程 **0~100 kPa 表压**（别买成 200/700kPa，分辨率变差）
  - 供电 5V 或 3.3~5V 兼容；I2C 地址 **0x6D**
  - 带 Φ4 气嘴（能插气管）
  - 注意模块上的 SCL/SDA 是否自带 5V 上拉——自带的话要么拆掉，要么加 BSS138 电平转换（见第 14 项）
- **必问客服**："是 I2C 数字输出吗？量程 0-100kPa 表压？SCL/SDA 上拉到几伏？"
- **参考价**：¥25~40

### 4. PU 气管套装
- **直搜词**：`PU气管 4mm 套装 快插接头 三通`
- **备选词**：`PU管 4x2.5 气动软管 T型三通 PE-4`
- **筛选要点**：
  - 管径 **外径 Φ4 / 内径 Φ2.5**
  - 套装里要有 **T 型三通（PE-4，三口都是 Φ4）×1 以上**
  - 顺手多买 1 个三通（¥1~2）——传感器取压分路更规整（见手套气路图）
- **参考价**：¥15~25

---

## 二、驱动与电源（洞洞板部分，大店一站购齐）

| # | 元件 | 直搜词（整段复制） | 筛选要点 | 参考价 |
|---|---|---|---|---|
| 5 | N-MOSFET | `IRLZ44N 场效应管 TO-220 直插` | 认准 **IRLZ44N**（L 是逻辑电平）；别买成 IRFZ44N（驱动电压不够） | ¥3~5 |
| 6 | 达林顿阵列 | `ULN2803APG DIP-18 直插` | DIP-18 直插封装 | ¥3 |
| 7 | IC 座 | `IC座 18P 圆孔 DIP18 插座` | 圆孔比扁孔好插 | ¥1 |
| 8 | 泵续流二极管 | `1N5822 肖特基二极管 直插` | 必须 **1N5822 肖特基**（泵是 PWM 驱动，慢管会发热）；买 5 个 | ¥1 |
| 9 | 阀续流二极管 | `1N4007 二极管 直插` | 买 10 个 | ¥1 |
| 10 | 电阻 | `1/4W 色环电阻 100欧 100K 4.7K` | 三种各几个；或买"常用电阻包 1/4W"一整包 | ¥3 |
| 11 | 3.3V 稳压 | `AMS1117-3.3 电源模块 5V转3.3V` | 买**模块**（4 针排针那种），免焊外围 | ¥1~2 |
| 12 | 电容 | `电解电容 100uF 25V` + `瓷片电容 104 50V` | 各几个 | ¥2 |
| 13 | 12V 电源 | `12V3A 电源适配器 5.5*2.1` | 必须 **12V/3A**，接口 **DC 5.5×2.1**（内正外负） | ¥20~30 |
| 14 | DC 转接线 | `DC5.5*2.1 母座转接线 免焊 带线` | 母座带红黑两根线的那种，免剪适配器线 | ¥3 |
| 15 | （备用）电平转换 | `BSS138 电平转换模块 2路 I2C` | 仅当传感器模块自带 5V 上拉拆不掉时买 | ¥2 |

---

## 三、结构件

| # | 元件 | 直搜词 | 筛选要点 | 参考价 |
|---|---|---|---|---|
| 16 | 洞洞板 | `洞洞板 9x15 双面喷锡 万能板` | 尺寸 9×15cm，双面喷锡好焊 | ¥3 |
| 17 | 接线端子 | `KF301-2P 接线端子 蓝色 5.08` | 2P 蓝色，买 3 个（气泵/V2/12V输入各一） | ¥3 |
| 18 | 杜邦线 | `杜邦线 公对母 40P 20cm` | 一定要 **公对母**（公头插 ATK 排针，母头插洞洞板排针） | ¥10 |
| 19 | 排针排母 | `单排针 2.54mm 40P` + `单排母 2.54mm 40P` | 各 1 条，掰着用 | ¥2 |
| 20 | 手套 | `棉线手套 劳保` 或 `乳胶手套 加厚` | 做气室外层，大一号方便塞气球 | ¥20~30 |
| 21 | 气球 | `加厚气球 大号 圆形` | 加厚款，买一包多试错 | ¥5~10 |
| 22 | 扎带热缩管 | `尼龙扎带 3x100` + `热缩管套装` | 扎带扎气球口密封用 | ¥5 |
| 23 | （可选）急停按钮 | `急停按钮 自锁 蘑菇头 红色` | 调试期用板载 KEY1(K16) 就够，可不买 | ¥8~12 |

---

## 四、下单顺序（照这个来，省钱且安全）

```
第一批 ¥~70  验证驱动电路：
  第 5~19 项（MOSFET/ULN2803/电阻/二极管/AMS1117/电容/12V电源/DC线/洞洞板/端子/杜邦线/排针排母）
  → 焊好空载测：杜邦3 拉高 → MOSFET D 极≈0V；杜邦4 拉高 → ULN2803 OUT1≈1V

第二批 ¥~110 气动联调：
  第 1~4 项（气泵/V2阀/传感器/气管）
  → LCD 看到压力读数，跑 充气→保压→泄气

第三批 ¥~35 上手套：
  第 20~22 项（手套/气球/扎带）
  → 瓶罐负载验证 OK 后才考虑上手，调试期严禁戴人手
```

## 五、三个"买错就翻车"汇总

1. **V2 阀必须常开 NO**（断电通气）→ 下单前问客服，到货断电吹一口气验证通不通
2. **传感器必须 I2C 数字版**（不是模拟电压版）→ 问客服，看商品名带 "I2C/数字"
3. **气泵截止压力 ≥150kPa**（不是流量大就行）→ 看参数表"最大压力/截止压力"

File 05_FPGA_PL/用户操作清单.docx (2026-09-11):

# 医用气动辅助手套 - PL 端工程用户操作清单

生成日期: 2026-05-12 (Rev: 免焊接简化方案) · 工程目录: D:\medical project\05_FPGA_PL端

# ★ 0. 本方案要点 (与之前不同的地方)

✅ 全程零焊接, 只用 ATK MODULE 排针 + 杜邦线 + 面包板

为了避免拆外壳焊接 ZYNQ 引脚, 已经做了以下精简:

1. 砍掉 V1 充气阀 → 气路简化为 pump → 手套 → V2(泄气阀) → 大气
2. 砍掉外接状态灯 → 用板载 LED0 (H15) 代替
3. 全部 4 个外设信号 (pump / V2 / 气压SCL / 气压SDA) 走 ATK MODULE 接口

影响: 元件清单少买 1 个电磁阀 (省 ¥10-20)
安全性: 不变 (fail-safe 来自 V2 是 NO 型, 断电自动开阀泄气)

# ★ 1. 代码审查 - 已知问题与已修复

问题 | 严重性 | 状态
lcd_display.v 中 img_addr 位宽只有 15 位, 最大 BROM 地址 34999 需要 16 位 | 严重 | ✓ 已修复
砍 V1 阀: 状态机、安全联锁、顶层、XDC 已同步删除 | 设计简化 | ✓ 已完成
全部信号走 ATK MODULE 接口, 完全免焊接 | 便利性 | ✓ 已完成
lcd_display 的 BROM 在区域外仍会被读 (无害, 只多耗一点点功耗) | 轻微 | 可不改
safety_interlock 是纯组合, 可能有 1~2ns 毛刺 | 轻微 | 设计意图 (响应最快)

# ★ 2. Vivado 2020.2 工程创建步骤

## 2.1 新建工程

1. Vivado 2020.2 → Create Project → Next
2. 工程名: medical_glove · 路径: D:\medical project\vivado_prj (自建)
3. Type: RTL Project (取消 "Do not specify sources at this time")
4. Add Sources: 添加 D:\medical project\05_FPGA_PL端 下 11 个干净版 .v 文件
5. Add Constraints: 添加 constraints\medical_glove.xdc
6. Default Part: xc7z020clg400-2
7. Finish

要添加的 .v 文件清单 (11 个):

- 00_top\medical_glove_top.v
- 01_clock_reset\clock_reset.v
- 02_key_debounce\key_debounce.v
- 03_lcd_timing\lcd_timing.v
- 04_lcd_display\lcd_display.v
- 05_touch_iic\touch_iic.v
- 06_pressure_iic\pressure_iic.v
- 07_pwm_ctrl\pwm_ctrl.v
- 08_glove_fsm\glove_fsm.v
- 09_safety_interlock\safety_interlock.v
- 10_axi_lite_reg\axi_lite_reg.v

⚠ 不要添加带 _annotated 后缀的文件 (同名 module 会冲突)

## 2.2 创建 IP 1: Clocking Wizard

8. Flow Navigator → IP Catalog → 搜 "Clocking Wizard" → 双击
9. Clocking Options: Source = Single ended clock capable pin, Source frequency = 50.000 MHz
10. Output Clocks: clk_out1=100.000, clk_out2=33.333, Reset Type=Active Low, 勾 locked
11. Component Name: clk_wiz_0 (默认, 不改)
12. OK → Generate Output Products

## 2.3 创建 IP 2: Block Memory Generator (图片 ROM)

13. IP Catalog → 搜 "Block Memory Generator" → 双击
14. Component Name: lcd_image_rom (必须这个名字)
15. Basic: Native + Single Port ROM
16. Port A: Width=16, Depth=35000, Enable Port Type=Always Enabled
17. Other Options: 勾 Load Init File → 选 ip_sources\lcd_image.coe → 等校验通过
18. OK → Generate

# ★ 3. Block Design (PS7 + EMIO GPIO)

19. Flow Navigator → IP INTEGRATOR → Create Block Design → 名字: system
20. 右键空白 → Add IP → 搜 "ZYNQ7 Processing System" → 双击
21. 双击 PS7 IP 进入配置:
22. PS-PL Configuration → General → Enable Clock Resets → 勾 FCLK_RESET0_N
23. PS-PL Configuration → AXI Non Secure → 勾 M_AXI_GP0
24. MIO Configuration → I/O Peripherals → GPIO: 勾 GPIO MIO + GPIO EMIO, EMIO Width=21
25. 保留 UART1 (Vitis 串口打印用)
26. 点 Run Block Automation → 自动接复位
27. 把 BD 当作子模块插入顶层 (system_wrapper) - 这一步留到 PS 端联调时做, 当前先跳过

💡 当前 medical_glove_top.v 的 PS 接口端口悬空也能综合, Vivado 报 warning 但不报 error

# ★ 4. 综合 → 实现 → 生成 Bitstream

28. Flow Navigator → SYNTHESIS → Run Synthesis (3-5 分钟)
29. 查 Reports → Timing → 看 WNS > 0
30. Flow Navigator → IMPLEMENTATION → Run Implementation (5-10 分钟)
31. Flow Navigator → PROGRAM AND DEBUG → Generate Bitstream (3-5 分钟)
32. 产物: vivado_prj\medical_glove.runs\impl_1\medical_glove_top.bit

# ★ 5. 导出硬件给 Vitis

33. File → Export → Export Hardware...
34. 勾 Include bitstream
35. 导出 medical_glove_top.xsa, 保存好下一步给 Vitis 用

# ★ 6. 物理接线 (重点看这节)

## 6.1 ATK MODULE 接口 (U4) - 整个项目唯一要插的开发板接口

找位置: 板上印有 "ATK MODULE" 字样的 6-pin 单排排针, 通常在板边/角落, 一定露在外壳外。

Pin | ZYNQ 引脚 | 信号名 | 接到面包板的什么
1 | N15 | pres_scl_o | XGZP6857D 气压传感器 SCL (经 4.7K 上拉到 +3.3V)
2 | G14 | pres_sda_io | XGZP6857D 气压传感器 SDA (经 4.7K 上拉到 +3.3V)
3 | T19 | pump_o | ULN2803 IN1 (Pin1)
4 | J15 | valve_v2_o | ULN2803 IN2 (Pin2)
5 | GND | - | 面包板的地轨
6 | +5V | - | 给 ULN2803 不用 (它无需 VCC), 给气压传感器 VIN

用 6 根杜邦线 (公-母, 一端接排针, 一端插面包板) 把这 6 个信号引出。
完全不动板上其他位置, 也不拆外壳。

## 6.2 面包板布局

ASCII 布局示意:

+3.3V 轨 ←── 来自气压传感器附带的 3.3V 输出 (或外接稳压)
+5V 轨 ←── ATK MODULE Pin6
GND 轨 ←── ATK MODULE Pin5
+12V 轨 ←── 外接 12V 电源正极 (给气泵/电磁阀用)

面包板上插:
· 1 块 ULN2803 (DIP18, 直接插)
· 1 块 XGZP6857D 气压传感器模块 (4-pin: VCC/GND/SDA/SCL)
· 2 个 4.7K 上拉电阻 (SDA→3.3V, SCL→3.3V)
· 1 个 2-针螺丝端子 (接气泵 +/−)
· 1 个 2-针螺丝端子 (接电磁阀 V2 +/−)
· 续流二极管 1N4007 各 1 颗 (并联在气泵/阀门两端)

## 6.3 ULN2803 接线 (DIP18 封装)

管脚定义:
IN1 (Pin1) ← ATK MODULE Pin3 (pump_o)
IN2 (Pin2) ← ATK MODULE Pin4 (valve_v2_o)
IN3-IN8 ← 悬空不接 (本项目用不到)
GND (Pin9) ← 面包板 GND 轨
COM (Pin10) ← 面包板 +12V 轨 (重要! 续流二极管的公共端)
OUT1 (Pin18) → 气泵的负极 (-)
OUT2 (Pin17) → 电磁阀 V2 的负极 (-)

气泵 正极 (+) ← 面包板 +12V 轨
阀门 V2 正极 (+) ← 面包板 +12V 轨
(实际接线: ULN2803 拉低 OUT 端 → 电流从 +12V → 气泵/阀门 → OUT → GND, 阀门动作)

## 6.4 气路 (砍 V1 后的简化版)

气路图:

[12V 气泵] → [手套气室] → [V2 电磁阀 NO 型] → 大气
|
└→ [XGZP6857D 气压传感器] (并联在气室上, T 型三通)

关键: V2 必须买 "NO 型常开" 电磁阀 (不通电时阀门开 = 自动泄气, fail-safe)
气路连接器用 PU4 气管 + 快插接头
气压传感器要带气管接头 (XGZP6857D 模块通常自带)

## 6.5 电源

本项目需要 3 路电源:

+3.3V: 给气压传感器 (从 ZYNQ 板上 3.3V 排针取, 几 mA)
+5V: 从 ATK MODULE Pin6 取 (备用, 实际不接也行)
+12V: 单独外接适配器 (1-2A), 给气泵和阀门用大电流

⚠ 不能从 ZYNQ 板拉 +12V (板上没有), 也不能从板上拿 +5V 接气泵 (会跳板)
⚠ +12V 适配器的 GND 必须和 ZYNQ 板 GND 共地 (面包板 GND 轨)

# ★ 7. 上电调试顺序 (从易到难)

阶段 1: 仅烧 bitstream, 不接任何外设

· 屏幕应该亮, 显示 UI: 顶部灰色状态栏 + 左绿右橙背景 + 中心 200x175 图片

· 黑屏排错: 看 lcd_pclk_o (P19) 和 lcd_bl_o (M20) 引脚是否正确

阶段 2: 验证图片显示

· 屏幕中心应该有 COE 转的图片

· 乱码: 检查 BROM IP COE 是否正确加载

阶段 3: 验证按键

· 按板载 KEY1 (K16) → 状态栏从灰色变红色 (EMERGENCY)

· 松开 KEY1 → 恢复灰色

阶段 4: 用万用表验证 ATK MODULE 输出 (不接外设)

· Pin3 (T19, pump_o): 静态应为低 (0V)

· Pin4 (J15, valve_v2_o): 静态应为低 (0V)

· 把 grip_req_i 临时 tied to 1 (改 RTL), 重新综合烧入 → Pin3/Pin4 应为高 (3.3V)

阶段 5: 接气压传感器, 验证 IIC

· 按 ATK MODULE Pin1/Pin2 接气压传感器 SCL/SDA + 4.7K 上拉

· 用手挤一下传感器进气口, 屏幕底部压力条应该变化

· 不变化: 检查传感器供电 + 上拉电阻 + IIC 地址 0x6D 是否正确

阶段 6: 接 ULN2803 + 气泵 + 阀门 (最后)

· 先用万用表量 ULN2803 OUT1/OUT2 在不同状态下的电平

· 验证无误后再接气泵, 短时通断

· 确认气泵能转、V2 能开关

· 调试期严禁戴在人手上

# ★ 8. 安全警告

- 压力硬上限 80 kPa: 软件 + 硬件 (safety_interlock 模块) 双保险
- 泄气阀 V2 必须是常开型 NO: 断电自动泄压, fail-safe
- 不是医疗器械, 禁止替代正规医疗用品
- 调试期严禁戴在人手上, 用气球或皮球模拟
- 气泵反冲电压可达 100V+, 一定要焊好 ULN2803 续流二极管 (或用 1N4007 并联在气泵两端)
- +12V 适配器必须独立, 不要从 ZYNQ 板拉电

# ★ 9. 元件清单变化

元件 | 原方案数量 | 新方案数量
NO 型常开电磁阀 (V2 泄气阀) | 1 | 1 (买 12V 直流型)
NC 型常闭电磁阀 (V1 充气阀) | 1 | ★ 0 (砍掉)
气泵 12V 直流 | 1 | 1
XGZP6857D 气压传感器模块 | 1 | 1
ULN2803APG (DIP18) | 1 | 1
面包板 (推荐 400 孔) | 建议有 | ★ 必备
6 根杜邦线 (公-母, 接 ATK MODULE) | - | ★ 必备
4.7K 电阻 | 2 | 2 (气压 IIC 上拉)
1N4007 续流二极管 | 3 | ★ 2 (一颗给气泵, 一颗给 V2)
12V 电源适配器 (1-2A) | 1 | 1
PU4 气管 + 三通 + 快插接头 | 若干 | 若干 (简化, 不需要 V1 相关三通)

# ★ 10. 下次找 AI 的关键词

下次新会话, 说以下任一句, AI 都能继续:

· "继续 PL 工程, 写 PS7 wrapper"
· "PL 端 bitstream 跑通了, 开始写 06_PS端软件"
· "PL 综合报错 [贴报错日志]"
· "气压读不到值, 帮我调"
· "想改回有 V1 的方案 (要焊接)"

AI 的 memory 已经记录了项目全部背景 (包括砍 V1 的决策), 不需要重新介绍。

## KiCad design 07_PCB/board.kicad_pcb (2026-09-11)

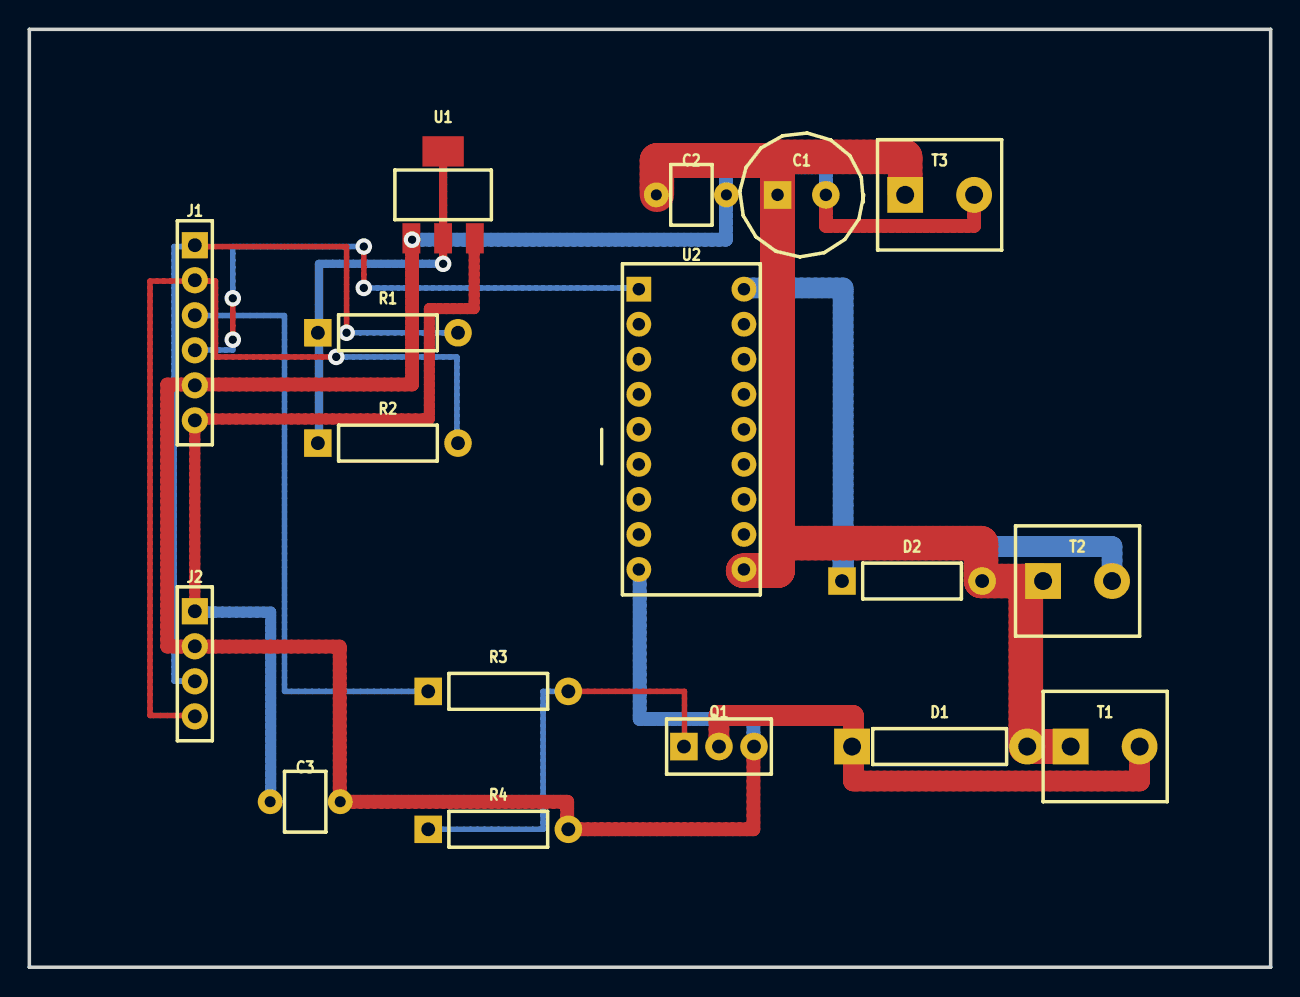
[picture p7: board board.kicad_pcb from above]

Board: 2 copper layers, 90.0 x 68.0 mm, 17 parts (0 on the bottom side), 11 nets.

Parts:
C1: ELEC
C2, C3: CER
D1: DO201AD
D2: DO41
J1: HDR6
J2: HDR4
Q1: TO220
R1, R2, R3, R4: AXIAL
T1, T2, T3: KF301
U1: SOT223
U2: DIP18

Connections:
+3.3V: R1.1, R2.1, U1.2, U1.4
+5V: C3.1, J1.6, J2.1, U1.3
+12V: C1.1, C2.1, D1.2, D2.2, T1.1, T2.1, T3.1, U2.10
GATE: Q1.1, R3.2, R4.1
GND: C1.2, C2.2, C3.2, J1.5, J2.2, Q1.3, R4.2, T3.2, U1.1, U2.9
PUMP: J1.3, R3.1
PUMP_D: D1.1, Q1.2, T1.2
SCL: J1.1, J2.3, R1.2
SDA: J1.2, J2.4, R2.2
VALVE: J1.4, U2.1
VALVE_OUT: D2.1, T2.2, U2.18

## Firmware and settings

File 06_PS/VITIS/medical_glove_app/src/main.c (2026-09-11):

#include <stdio.h>
#include "xparameters.h"
#include "xgpiops.h"
#include "sleep.h"
#include "touch.h"
#include "emio_iic_cfg.h"

#define PSGPIO_DEVICE_ID XPAR_PS7_GPIO_0_DEVICE_ID
#define PS_LED0_MIO      7
#define PS_LED1_MIO      8

/* ==========================================================================
 * EMIO GPIO 映射 (与 PL system_top.v 严格一致)
 *   XGpioPs Pin = 54 + EMIO 索引;  XGpioPs bank2 = EMIO[31:0]
 *   输出 (PS->PL):  EMIO[0] = grip_req, EMIO[1] = release_req
 *                   EMIO[17:2] = setpoint (单位 0.01kPa)
 *   输入 (PL->PS):  EMIO[15:0]  = pressure (0.01kPa)
 *                   EMIO[18:16] = fsm_state, EMIO[19] = safety_trigger
 *                   EMIO[20]    = sensor_fault
 * 用 bank2 整bank 读写: 一次 32bit 原子操作, 避免逐位写中间态。
 * ========================================================================== */
#define EMIO_BANK        2
#define BIT_GRIP         0x1u        /* bank2 bit0 = EMIO[0] */
#define BIT_RELEASE      0x2u        /* bank2 bit1 = EMIO[1] */
#define SETPOINT_SHIFT   2           /* setpoint 从 bit2 开始 */

/* 目标压力, 单位 0.01kPa: 5000 = 50.00 kPa
 * 允许范围 3000~8000 (30~80kPa); 必须 > FSM 回差 200, 且 < 安全联锁 8000 */
#define SETPOINT_X100_KPA  5000

/* 触摸区域 (基于 tp_dev 坐标系, 实测映射):
 *   物理X = tp_dev.y (0~800, 左->右),  物理Y = 480 - tp_dev.x (0~480, 上->下)
 * LCD 布局: 左半浅绿 = 收缩(GRIP), 右半浅橙 = 舒张(RELEASE), 顶部 y<50 状态条
 * 有效区 = 左右两个大半屏 (大触摸目标, 方便手部无力患者), 仅排除状态条/下边缘
 */
#define ZONE_MID_X      400   /* tp_dev.y < 400 = 左半屏(收缩), >=400 右半(舒张) */
#define ZONE_TX_MAX     430   /* tp_dev.x < 430 -> 物理Y > 50, 排除顶部状态条 */
#define ZONE_TX_MIN      10   /* tp_dev.x > 10  -> 物理Y < 470, 排除下边缘 */

/* ==========================================================================
 * 无阻塞 DCC 打印 (2026-08-02 重要修正)
 * 本 BSP 的 stdout = JTAG DCC (ps7_coresight_comp_0): 标准 printf 会
 * 忙等 DCC 发送空位, 而"空位"需要调试器经 JTAG 读走数据才会释放 ——
 * 脱机运行(不接调试器)时, printf 第 2 个字符起就永久卡死整个程序!
 * 所以绝不能用 printf, 必须逐字符带超时发送: 调试器在线时正常显示,
 * 脱机时自动丢弃, 绝不阻塞。指令序列与 BSP 驱动 xcoresightpsdcc.c 一致。
 * ========================================================================== */
#define DCC_STATUS_TXFULL  (1u << 29)   /* DBGDSCR TX 满标志 */
#define DCC_TIMEOUT        20000u       /* 每字符忙等上限 (约 300us @667MHz) */

static inline u32 dcc_status(void)
{
    u32 s;
    asm volatile("mrc p14, 0, %0, c0, c1, 0" : "=r" (s) :: "cc");
    return s;
}

/* 发送 1 字符; 返回 0 = 超时(无人接收, 放弃) */
static int dcc_putc(char c)
{
    u32 timeout = DCC_TIMEOUT;
    while (dcc_status() & DCC_STATUS_TXFULL) {
        if (timeout-- == 0u)
            return 0;
    }
    asm volatile("mcr p14, 0, %0, c0, c5, 0" :: "r" ((u32)(u8)c) : "cc");
    return 1;
}

static void dcc_puts(const char *s)
{
    while (*s) {
        if (!dcc_putc(*s++))
            return;                 /* 无人接收: 丢弃本条剩余内容 */
    }
}

static XGpioPs GpioPs;
static u32     emio_shadow = 0;   /* bank2 输出影子寄存器 */

static void ps_led0(int on) { XGpioPs_WritePin(&GpioPs, PS_LED0_MIO, on ? 1 : 0); }
static void ps_led1(int on) { XGpioPs_WritePin(&GpioPs, PS_LED1_MIO, on ? 1 : 0); }

/* 影子寄存器 -> 硬件: 一次 32bit 原子写入 */
static void emio_apply(void)
{
    XGpioPs_Write(&GpioPs, EMIO_BANK, emio_shadow);
}

/* 写目标压力 (bit[17:2]), 不影响 grip/release 两位 */
static void ps_write_setpoint(u16 sp_x100kpa)
{
    emio_shadow = (emio_shadow & 0x3u) | (((u32)sp_x100kpa) << SETPOINT_SHIFT);
    emio_apply();
}

/* 写请求位 (bit[1:0]): 0=无, BIT_GRIP=抓握, BIT_RELEASE=释放; 不影响 setpoint */
static void ps_write_request(u32 req_bits)
{
    emio_shadow = (emio_shadow & ~0x3u) | (req_bits & 0x3u);
    emio_apply();
}

int main(void)
{
    XGpioPs_Config *psCfg = XGpioPs_LookupConfig(PSGPIO_DEVICE_ID);
    XGpioPs_CfgInitialize(&GpioPs, psCfg, psCfg->BaseAddr);

    /* LED 初始化 */
    XGpioPs_SetDirectionPin(&GpioPs, PS_LED0_MIO, 1);
    XGpioPs_SetOutputEnablePin(&GpioPs, PS_LED0_MIO, 1);
    XGpioPs_SetDirectionPin(&GpioPs, PS_LED1_MIO, 1);
    XGpioPs_SetOutputEnablePin(&GpioPs, PS_LED1_MIO, 1);

    /* EMIO[0..17] = XGpioPs pin 54..71, 全部设为输出 (grip/release/setpoint) */
    for (int i = 0; i < 18; i++) {
        XGpioPs_SetDirectionPin(&GpioPs, 54 + i, 1);
        XGpioPs_SetOutputEnablePin(&GpioPs, 54 + i, 1);
    }

    ps_led0(0);
    ps_led1(0);

    /* 请求清零 + 写入目标压力 (修复: 旧代码从未写 setpoint, FSM 目标恒 0) */
    emio_shadow = 0;
    ps_write_setpoint(SETPOINT_X100_KPA);

    emio_init();   /* 触摸 I2C 口 (EMIO[54:57] = pin 108~111) */

    /* 启动信号：LED0 快闪 3 次 */
    for (int i = 0; i < 3; i++) {
        ps_led0(1); usleep(100000);
        ps_led0(0); usleep(100000);
    }

    /* 注意: FT5206_Init/S_scan 实际驱动的是 GT911/9147 ("911" 分支),
     * 函数名是历史遗留; 触摸通信 2026-05-21 已在硬件验证, 勿动 */
    TP_Init();

    /* TP_Init 完成：LED1 亮 2 秒 */
    ps_led1(1); usleep(2000000); ps_led1(0);

    dcc_puts("glove app start, setpoint = 50.00 kPa\r\n");

    const char *state_name[8] = { "IDLE", "GRIP", "HOLD", "RELEASE",
                                  "EMERGENCY", "?", "?", "?" };
    int tick = 0;
    int heartbeat = 0;
    char msg[96];

    while (1) {
        tp_dev.scan(0);

        if (tp_dev.sta & TP_PRES_DOWN) {
            ps_led1(1);  /* 触摸中，LED1 亮 */

            u16 tx = tp_dev.x[0];  /* 0~480, 物理Y = 480 - tx */
            u16 ty = tp_dev.y[0];  /* 0~800 = 物理X, 越大越靠右 */

            if (tx > ZONE_TX_MIN && tx < ZONE_TX_MAX) {
                /* 左半屏(浅绿) = 收缩, 右半屏(浅橙) = 舒张, 与 LCD 显示一致 */
                if (ty < ZONE_MID_X)
                    ps_write_request(BIT_GRIP);
                else
                    ps_write_request(BIT_RELEASE);
            }
        } else {
            ps_led1(0);  /* 无触摸，LED1 灭 */
            /* 触摸抬起清零请求; GRIP/HOLD/RELEASE 状态由 PL FSM 自保持 */
            ps_write_request(0);
        }

        /* 每 500ms: 读 PL 反馈 + LED0 状态指示 + 无阻塞打印 */
        if (++tick >= 25) {
            tick = 0;
            u32 bank2  = XGpioPs_Read(&GpioPs, EMIO_BANK);
            u16 pres   = bank2 & 0xFFFF;
            u8  st     = (bank2 >> 16) & 0x7;
            u8  safety = (bank2 >> 19) & 0x1;
            u8  fault  = (bank2 >> 20) & 0x1;

            /* LED0: 传感器故障时常亮(醒目), 正常时 1Hz 心跳(证明程序活着) */
            if (fault) {
                ps_led0(1);
            } else {
                heartbeat ^= 1;
                ps_led0(heartbeat);
            }

            snprintf(msg, sizeof(msg), "P=%d.%02dkPa state=%s safety=%d fault=%d\r\n",
                     pres / 100, pres % 100, state_name[st], safety, fault);
            dcc_puts(msg);
            if (fault)
                dcc_puts("!! 气压传感器通信失败, 已自动停泵泄气, 请检查传感器接线\r\n");
        }

        usleep(20000);  /* 20ms 轮询 */
    }
    return 0;
}

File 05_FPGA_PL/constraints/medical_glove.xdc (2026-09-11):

#-----------------------------------------------------------------------------
# Medical Glove PL Constraints
# Version: 2026-08-02  增加显式主时钟约束 (原依赖 clk_wiz PRIM_IN_FREQ 自动衍生)
#-----------------------------------------------------------------------------

#-----------------------------------------------------------------------------
# 1. 系统时钟 50MHz
#-----------------------------------------------------------------------------
set_property -dict {PACKAGE_PIN U18 IOSTANDARD LVCMOS33} [get_ports sys_clk_i]
create_clock -period 20.000 -name sys_clk [get_ports sys_clk_i]

#-----------------------------------------------------------------------------
# 2. 复位键 KEY_RST
#-----------------------------------------------------------------------------
set_property -dict {PACKAGE_PIN N16 IOSTANDARD LVCMOS33} [get_ports sys_rst_n_i]

#-----------------------------------------------------------------------------
# 3. 急停按键 PL_KEY1
#-----------------------------------------------------------------------------
set_property -dict {PACKAGE_PIN K16 IOSTANDARD LVCMOS33 PULLUP true} [get_ports emerg_key_i]

#-----------------------------------------------------------------------------
# 4. LCD RGB888 (ATK-MD0700R 7" 800x480)
#-----------------------------------------------------------------------------
set_property -dict {PACKAGE_PIN W18 IOSTANDARD LVCMOS33} [get_ports {lcd_rgb_o[0]}]
set_property -dict {PACKAGE_PIN W19 IOSTANDARD LVCMOS33} [get_ports {lcd_rgb_o[1]}]
set_property -dict {PACKAGE_PIN R16 IOSTANDARD LVCMOS33} [get_ports {lcd_rgb_o[2]}]
set_property -dict {PACKAGE_PIN R17 IOSTANDARD LVCMOS33} [get_ports {lcd_rgb_o[3]}]
set_property -dict {PACKAGE_PIN W20 IOSTANDARD LVCMOS33} [get_ports {lcd_rgb_o[4]}]
set_property -dict {PACKAGE_PIN V20 IOSTANDARD LVCMOS33} [get_ports {lcd_rgb_o[5]}]
set_property -dict {PACKAGE_PIN P18 IOSTANDARD LVCMOS33} [get_ports {lcd_rgb_o[6]}]
set_property -dict {PACKAGE_PIN N17 IOSTANDARD LVCMOS33} [get_ports {lcd_rgb_o[7]}]
set_property -dict {PACKAGE_PIN V17 IOSTANDARD LVCMOS33} [get_ports {lcd_rgb_o[8]}]
set_property -dict {PACKAGE_PIN V18 IOSTANDARD LVCMOS33} [get_ports {lcd_rgb_o[9]}]
set_property -dict {PACKAGE_PIN T17 IOSTANDARD LVCMOS33} [get_ports {lcd_rgb_o[10]}]
set_property -dict {PACKAGE_PIN R18 IOSTANDARD LVCMOS33} [get_ports {lcd_rgb_o[11]}]
set_property -dict {PACKAGE_PIN Y18 IOSTANDARD LVCMOS33} [get_ports {lcd_rgb_o[12]}]
set_property -dict {PACKAGE_PIN Y19 IOSTANDARD LVCMOS33} [get_ports {lcd_rgb_o[13]}]
set_property -dict {PACKAGE_PIN P15 IOSTANDARD LVCMOS33} [get_ports {lcd_rgb_o[14]}]
set_property -dict {PACKAGE_PIN P16 IOSTANDARD LVCMOS33} [get_ports {lcd_rgb_o[15]}]
set_property -dict {PACKAGE_PIN V16 IOSTANDARD LVCMOS33} [get_ports {lcd_rgb_o[16]}]
set_property -dict {PACKAGE_PIN W16 IOSTANDARD LVCMOS33} [get_ports {lcd_rgb_o[17]}]
set_property -dict {PACKAGE_PIN T14 IOSTANDARD LVCMOS33} [get_ports {lcd_rgb_o[18]}]
set_property -dict {PACKAGE_PIN T15 IOSTANDARD LVCMOS33} [get_ports {lcd_rgb_o[19]}]
set_property -dict {PACKAGE_PIN Y17 IOSTANDARD LVCMOS33} [get_ports {lcd_rgb_o[20]}]
set_property -dict {PACKAGE_PIN Y16 IOSTANDARD LVCMOS33} [get_ports {lcd_rgb_o[21]}]
set_property -dict {PACKAGE_PIN T16 IOSTANDARD LVCMOS33} [get_ports {lcd_rgb_o[22]}]
set_property -dict {PACKAGE_PIN U17 IOSTANDARD LVCMOS33} [get_ports {lcd_rgb_o[23]}]

set_property -dict {PACKAGE_PIN N18 IOSTANDARD LVCMOS33} [get_ports lcd_hsync_o]
set_property -dict {PACKAGE_PIN T20 IOSTANDARD LVCMOS33} [get_ports lcd_vsync_o]
set_property -dict {PACKAGE_PIN U20 IOSTANDARD LVCMOS33} [get_ports lcd_de_o]
set_property -dict {PACKAGE_PIN M20 IOSTANDARD LVCMOS33} [get_ports lcd_bl_o]
set_property -dict {PACKAGE_PIN P19 IOSTANDARD LVCMOS33} [get_ports lcd_pclk_o]

#-----------------------------------------------------------------------------
# 5. 触摸 I2C (GT911) - 由 PS EMIO GPIO + 软件位bang I2C 驱动
#    SCL/SDA/RST/INT 均为 EMIO[54:57]，经 IOBUF 三态缓冲器连到物理引脚
#    PS 端通过 XGpioPs_SetOutputEnablePin() 控制方向（反映到 GPIO_T）
#-----------------------------------------------------------------------------
set_property -dict {PACKAGE_PIN R19 IOSTANDARD LVCMOS33 PULLUP true} [get_ports tp_scl_io]
set_property -dict {PACKAGE_PIN P20 IOSTANDARD LVCMOS33 PULLUP true} [get_ports tp_sda_io]
set_property -dict {PACKAGE_PIN M19 IOSTANDARD LVCMOS33}             [get_ports tp_rst_io]
set_property -dict {PACKAGE_PIN U19 IOSTANDARD LVCMOS33 PULLUP true} [get_ports tp_int_io]

#-----------------------------------------------------------------------------
# 6. ATK MODULE 接口 (U4) - 气压 I2C + 气泵/阀门
#-----------------------------------------------------------------------------
set_property -dict {PACKAGE_PIN N15 IOSTANDARD LVCMOS33 PULLUP true} [get_ports pres_scl_o]
set_property -dict {PACKAGE_PIN G14 IOSTANDARD LVCMOS33 PULLUP true} [get_ports pres_sda_io]
set_property -dict {PACKAGE_PIN T19 IOSTANDARD LVCMOS33}              [get_ports pump_o]
set_property -dict {PACKAGE_PIN J15 IOSTANDARD LVCMOS33}              [get_ports valve_v2_o]
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
